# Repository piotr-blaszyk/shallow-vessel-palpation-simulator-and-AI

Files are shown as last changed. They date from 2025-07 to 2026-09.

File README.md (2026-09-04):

# Robot-Assisted Sliding Palpation for Shallow Vessel Localisation with a Calibrated Digital Twin

Locating features **hidden beneath a soft surface** — blood vessels in a silicone phantom,
straws buried under layers of steak — from the deformation of the marker grid of a ViTacTip
optical tactile sensor sliding over it.

The core question: **can a model trained entirely in simulation localise subsurface structure
in the real world?** A digital twin (a Taichi FEM simulation of the sensor pressing on a
phantom with a stiff inclusion) is calibrated against the real sensor by Bayesian optimisation,
generates labelled marker trajectories, and a spatio-temporal graph neural network trained only
on those is evaluated on video from the physical sensor — per marker, and as a top-view vessel
map.

This is a masters project, and a fork of [DiffTactile](https://difftactile.github.io/)
(Si et al., ICLR 2024): the upstream manipulation tasks were removed and the differentiable FEM
core repurposed. The pristine upstream state is preserved at the `upstream-difftactile` tag.

### Project repositories and data

The manuscript — *"Toward Trustworthy Robot-Assisted Sliding Palpation for Shallow Vessel
Localisation with a Calibrated Digital Twin"* — is backed by two repositories and one data
archive:

| Artefact | Role |
|---|---|
| **[shallow-vessel-palpation-simulator-and-AI](https://github.com/piotr-blaszyk/shallow-vessel-palpation-simulator-and-AI)** (this one), DOI [10.5281/zenodo.21958186](https://doi.org/10.5281/zenodo.21958186) | **Main repository.** Simulator, domain adaptation, dataset generation, GNN training and evaluation, all figures and tables — everything needed to reproduce the published results. |
| [shallow-vessel-palpation-robot-control](https://github.com/piotr-blaszyk/shallow-vessel-palpation-robot-control), DOI [10.5281/zenodo.21958190](https://doi.org/10.5281/zenodo.21958190) | Drives the DOBOT Magician E6 arm that collected the real tactile recordings. Needed only to *gather new* data. |
| Zenodo **shallow-vessel-palpation-dataset**, DOI [10.5281/zenodo.21958107](https://doi.org/10.5281/zenodo.21958107) | Datasets, trained checkpoints and the manuscript's figures/tables (~275 MB). See [Data](#data-the-zenodo-bundle). |
| Project page: [piotr-blaszyk.github.io/shallow-vessel-palpation-simulator-and-AI](https://piotr-blaszyk.github.io/shallow-vessel-palpation-simulator-and-AI/) | Abstract and all videos in one place (`docs/`). |

```
   Taichi FEM digital twin                 Real ViTacTip sensor
   sensor + phantom + vessel               video, sliding over the phantom
   (calibrated by Bayesian optimisation)             │
            │                                        ▼
   simulated marker trajectories        tracked marker trajectories
            │                                        │
            └──────────────► ST-GNN ◄────────────────┘
                        train on Sim         test on Sim / Silicone / Meat
                              │
                              ▼
        per-marker vessel probability  ──►  top-view vessel map (1 mm/px)
```

---

## Quickstart (Docker)

**Docker is the only supported way to run this repository.** The image pins the whole stack
(CUDA 12.6, Taichi, PyTorch 2.8 + PyTorch Geometric, PySide6) and passes the host display
through so the simulator's windows work.

**Requirements:** Linux with an NVIDIA GPU (a must), the NVIDIA driver, Docker and the
[NVIDIA Container Toolkit](https://docs.nvidia.com/datacenter/cloud-native/container-toolkit/latest/install-guide.html).
Developed and tested on **Ubuntu 24.04** with an **NVIDIA GeForce RTX 3080 (10 GB)**. Since the
whole stack lives inside the container (Ubuntu 22.04 base image), the host only needs the three
items above, so other Ubuntu releases — including older ones such as 18.04 / 20.04 — should work
too (untested; the optional bare-metal annotator env, `annotate_data_bare_metal.sh`, needs
PySide6 wheels and hence glibc ≥ 2.28, i.e. Ubuntu 20.04+). Less GPU RAM than 10 GB will likely
work as well: the GNN training uses little; the Taichi simulator is the main consumer, and its
budget is set by `TI_DEVICE_MEMORY_GB` (see Troubleshooting). `main` is the only branch.

```bash
# 1. Clone
git clone https://github.com/piotr-blaszyk/shallow-vessel-palpation-simulator-and-AI.git
cd shallow-vessel-palpation-simulator-and-AI

# 2. Fetch the data bundle (~275 MB) and unpack it into place
wget https://zenodo.org/records/21958107/files/shallow-vessel-palpation-data.tar.gz
./data/restore_data.sh shallow-vessel-palpation-data.tar.gz

# 3. Build the image (~10-30 min), start the container, open a shell inside it
cd docker
./docker-build.sh
./docker-run.sh
./docker-connect.sh

# 4. INSIDE the container: verify GPU, dependencies and data
cd docker
./run_pipeline.sh check
```

> **Everything below runs inside the container, from its `docker/` directory**, unless a
> command says otherwise. Every in-container command is equivalent to
> `docker exec -it vessel-palpation ./docker/<script> <args>` from the host. Three scripts are
> launched **from the host** and `docker exec` in by themselves (`view_predictions.sh`,
> `annotate_data_docker.sh`, `record_videos.sh`), and one runs on **bare metal by design**
> (`annotate_data_bare_metal.sh`).

### The pipeline at a glance

Steps 1–2 are done and their outputs ship in the bundle, as do the simulated dataset (step 4)
and the trained models (step 5), so a fresh clone can start anywhere.

1. **Preprocess the real recordings** (Silicone, Meat) → [Real datasets](#real-datasets-annotate-review-preprocess).
2. **Calibrate the digital twin** (`./domain_adaptation.sh`) and adopt the fitted parameters into
   `system-params.json`; draw the validation panels (`./alignment_figures.sh`) →
   [Domain adaptation](#domain-adaptation-calibrating-the-digital-twin).
3. **Pick the temporal window** (`./ablation_clip_len.sh`).
4. **Generate the simulated dataset** (`./run_pipeline.sh sim-full` + reorder) →
   [Regenerate the simulated dataset](#regenerate-the-simulated-dataset).
5. **Train and evaluate the four models** (`./score_all_scenarios.sh --seeds 5`, or one
   configuration with `./run_pipeline.sh <config> --train`) →
   [Reproduce the published results](#reproduce-the-published-results).
6. **Render the qualitative results**: `./vessel_map_all.sh` (top-view maps),
   `./view_predictions.sh` (per-frame viewer), `./record_videos.sh` (the videos below).
7. **Reproduce the poster's analysis** (`./reproduce_analysis.sh`) → [Which script produces
   which figure or table on the poster](#which-script-produces-which-figure-or-table-on-the-poster).

### Which script produces which figure or table in the manuscript

| Script | Produces | Manuscript |
|---|---|---|
| `./annotate_data_bare_metal.sh --silicone` / `--meat` | the annotation viewers | **Fig. 5** (annotated Silicone frame, Meat labels) |
| `./domain_adaptation.sh` → `./alignment_figures.sh` | joint BO calibration; sim (red) vs real (green) marker alignment on the four validation interactions, MAE per panel | **Fig. 4** and the 0.50 mm MAE |
| `./ablation_clip_len.sh` | foreground IoU / AP per temporal window length, mean ± std over seeds | **Table 3** |
| `./score_all_scenarios.sh --seeds 5` | five-seed sweep of every configuration: mean PR curves ± 1 std (ROC twins too), the standalone shared legend (`curve_legend.pdf`) and x label (`xlabel_recall.pdf`), `AUROC_RESULTS.md`, `sweep.json`; `--replot` redraws the curves and legend of an existing sweep without training | **Fig. 6** |
| `python -m difftactile.scripts.script_frame_space_metrics` | per-marker statistics of each best-of-five model, pooled over all central frames → `FRAME_SPACE_METRICS.md` | **Table 4**, upper half |
| `./vessel_map_all.sh` | top-view vessel maps and per-pixel statistics for every configuration | **Fig. 7**, **Table 4** lower half |
| `./record_videos.sh` | the [demonstration videos](#demonstration-videos) | supplementary |
| `./sensor_mesh_screenshots.sh` | three Gmsh screenshots of the ViTacTip mesh from the +x side (level, 45° above, 45° below), lossless WebP in `docs/images/sensor_mesh/` | project page only |

Every mean ± std quotes the five seeds of the published sweep (`saved_models_sweeps/20260815-194045`);
wherever a **single** model is shown or tabulated it is that configuration's **best-of-five
instance by average precision** (`cnn/model_selection.py`) — the convention the manuscript states.

### Which script produces which figure or table on the poster

The conference **poster** reports more than the manuscript: the same four models scored as a
*detection* problem (counts, Hungarian matching, F1 and OSPA), a per-vessel
centreline/centroid decomposition, and a baseline comparison in which **our own predictions
are recomputed under each baseline's own metric definition** rather than being printed beside
numbers that measure a different quantity. All of it lives in
[`analysis/`](analysis/) and is regenerated by one wrapper:

```bash
./docker/reproduce_analysis.sh                  # stages 1-12: every poster figure and number
./docker/reproduce_analysis.sh --with-overlays  # + per-data-point diagnostic overlays (~15 min)
./docker/reproduce_analysis.sh --list           # the stage table
./docker/reproduce_analysis.sh --only 4,7       # re-run individual stages
```

It trains nothing and simulates nothing: it evaluates the four published checkpoints once,
reads the published top-view map runs off disk, and derives everything else from those two.
A full pass is about two minutes, and needs a GPU **for stage 1 only** — the Zenodo bundle
also ships stage 1's output (`analysis/results/frame_space_predictions_<config>.npz`), so
stages 2–12 run on a CPU-only machine. Those four files are the only part of the bundle
`data/restore_data.sh --verify` reports as *regenerable* rather than *missing*: an older
download that predates them still restores cleanly, it just needs
`./docker/reproduce_analysis.sh --only 1` (one GPU minute) run first.

| Poster block | Artefact under `analysis/` | Script (stage) |
|---|---|---|
| **Methods** — *Workflow*: sensor, mesh, simulated interactions, domain randomisation, real datasets, annotation | `figures/workflow/{vitactip,mesh,A1,A2,B1,B2,B3,dr_*,real_*,ann_*}.png` | `make_workflow_images.py` (12) |
| **Methods** — *Workflow*: per-frame prediction block | `figures/workflow/pred_sim_to_meat.png` | `select_sim_to_meat_frames.py` (11) → `make_workflow_images.py` (12) |
| **Methods** — *Workflow*: *Top-view vessel maps* row | `figures/workflow/map_*.png` | `make_workflow_images.py` (12), copied from the published map runs |
| **Methods** — *Workflow*: *Frame-space vessel centrelines and centroids* | `figures/workflow/cl_grid_<0..3>_<config>.png`, `cl_legend.png`, `frame_grid.tex` | `detection_ospa.py` (4) → `workflow_centreline_panels.py` (10) |
| **Methods** — *Workflow*: *Top-view-space vessel centrelines and centroids* | `figures/workflow/cl_map_<config>.png` | `detection_ospa.py` (4) → `workflow_centreline_panels.py` (10) |
| **Methods** — *ST-GNN input graph* | `figures/gnn_graph.png` | `gnn_graph_figure.py` (9) |
| **Results** — take-home box (1.2 mm; AP 0.32 vs 0.30) | `results/symmetric_distances.json`, `figures/pr/ap_values.json` | `symmetric_distances.py` (2), `pr_curves_with_ap.py` (8) |
| **Results** — *Comparison against baselines*, our half of every row | `results/comparable_metrics.json`, `results/symmetric_distances.json` | `comparable_metrics.py` (3), `symmetric_distances.py` (2) |
| **Results** — *Centreline detection and localisation* | `figures/detection_bars.pdf` | `detection_ospa.py` (4) → `detection_bars.py` (7) |
| **Results** — *Segmentation distance* | `figures/segmentation_distance.pdf` | `symmetric_distances.py` (2) → `segmentation_bars.py` (6) |
| **Results** — *Vessel-count confusion* | `figures/detection_confusion.tex` | `detection_ospa.py` (4) → `detection_bars.py` (7) |
| **Results** — *Vessel present or absent* | `figures/binary_confusion.pdf` | `detection_bars.py` (7) |
| **Results** — *Precision–recall curves* | `figures/pr/mean_pr_curve_<config>.pdf`, `curve_legend_vertical.pdf`, `xlabel_recall.pdf` | `pr_curves_with_ap.py` (8) |
| **Results** — *Foreground IoU* | `figures/segmentation_iou.pdf` | `symmetric_distances.py` (2) → `segmentation_bars.py` (6) |

Three poster blocks are **not** repository output and have no script: the Motivation
illustration (hand-made), the *Vessel-detection modalities* table (literature values; the
fully cited version is published at
[`docs/poster-motivation-bibliography/`](docs/poster-motivation-bibliography/)), and the
baselines' own half of the comparison table (read out of each cited paper's full text).

[`analysis/README.md`](analysis/README.md) carries the per-script input/output table, the
self-checks the pipeline performs, the parameters that are judgements rather than fits
(the 5 mm OSPA cutoff, the 2:1 false-alarm/miss weighting, the 3 mm peak-splitting rule)
and the caveats that belong beside every number.

---

## Reproduce the published results

**Naming.** The code uses **A / B / C** for the three datasets; the manuscript spells them out.
`X-to-Y` reads "trained on X, tested on Y":

| Code | Manuscript | Dataset |
|---|---|---|
| **A** | **Sim** | 500 simulated slides (250 with / 250 without the vessel), 317 frames each |
| **B** | **Silicone** | real silicone phantom with shallow vessels: 10 annotated straight-line slides |
| **C** | **Meat** | real meat phantom (metal / silicone straws under 5 mm steaks): 10 trials |

Four (train → test) configurations, each selected **by name** and run either from the published
checkpoint (`--eval`) or retrained (`--train`):

| Config | Manuscript | Model | Default | AUROC | AP | FG IoU | BG IoU |
|---|---|---|---|---|---|---|---|
| `A-to-A` | Sim→Sim | large | `--eval` | 0.958 ± 0.001 | 0.491 ± 0.006 | 0.193 ± 0.019 | 0.818 ± 0.024 |
| `A-to-B` | Sim→Silicone | large | `--eval` | 0.779 ± 0.004 | 0.321 ± 0.004 | 0.234 ± 0.007 | 0.811 ± 0.027 |
| `A-to-C` | Sim→Meat | large | `--eval` | 0.837 ± 0.002 | 0.224 ± 0.004 | 0.171 ± 0.006 | 0.730 ± 0.019 |
| `C-to-B` | Meat→Silicone | compact | `--train` | 0.717 ± 0.054 | 0.304 ± 0.038 | 0.155 ± 0.012 | 0.537 ± 0.124 |

Mean ± std over the five seeds of the published sweep; per-marker over every central frame of
every test trial; IoU at threshold 0.5. `large` is `GNN(arch="large")` (`latent_dim` 256, the
`*_large` keys of the `gnn` config block), `compact` is `latent_dim` 64; a checkpoint only loads
into the architecture it was trained with. `A-to-A`, `A-to-B` and `A-to-C` score the **same**
sim-trained checkpoint on three test sets — the A→A → A→B gap is the sim-to-real transfer cost.

```bash
./run_pipeline.sh A-to-B                 # evaluate the published checkpoint (default for A-to-*)
./run_pipeline.sh C-to-B                 # train on meat, test on silicone (default for C-to-B)
./run_pipeline.sh A-to-C --train         # retrain any configuration from scratch
./run_pipeline.sh all-scenarios          # the four in sequence

./score_all_scenarios.sh                 # one table for all configurations -> AUROC_RESULTS.md
./score_all_scenarios.sh --pretrained    # published checkpoints only
./score_all_scenarios.sh --seeds 5       # retrain each configuration per seed: mean ± std,
                                         # mean PR/ROC curves, saved_models_sweeps/<TS>/
./score_all_scenarios.sh --replot        # redraw the published sweep's mean curves + the
                                         # shared threshold legend from saved scores (no training)
```

Each run prints AUROC, AP (with its chance level and lift) and both IoUs, and writes
`roc_curve_<config>.pdf` / `pr_curve_<config>.pdf` under `difftactile/output/`.
The older names `sim-to-silicone`, `sim-to-meat`, `silicone-to-meat` are accepted as aliases
(the last is a misnomer for A→C). The configuration and mode can also come from
`DIFFTACTILE_SCENARIO` / `DIFFTACTILE_MODE`.

**Training never overwrites the published checkpoints.** A `--train` run writes
`*_retrained_<config>` artifacts (`saved_models_sim/final_segmentation_model_gnn_sim_retrained_A-to-B.pt`
and its `test_loader_gnn_sim_retrained_A-to-B.pickle`, etc.); `DIFFTACTILE_OVERWRITE_PUBLISHED=1`
replaces the published files instead. A checkpoint and its test-loader pickle always travel
together — the pickle holds the normalisation statistics the checkpoint was trained with, and
mismatching them is a silent wrong answer, not an error.

**Metrics.** AUROC and AP are threshold-free (they read only the ranking of the probabilities,
so a domain shift of the output *scale* cannot masquerade as ignorance of where the vessels
are). They are reported together because AUROC normalises false alarms by the huge negative
count while AP ignores true negatives entirely and its chance level is the positive rate
(4–11% here) — the two can disagree in rank, and did on earlier checkpoints. IoU is per class
over the same marker predictions: **foreground** = vessel-present class
(`|pred ∧ true| / |pred ∨ true|`), **background** = vessel-absent class, always the flattering
one (the negative class is ~89% of nodes on Silicone, ~93% on Meat). Unlike AUROC/AP it depends
on the 0.5 threshold. This is the per-marker IoU; the top-view map has its own.

**Seeds.** Training is deterministic (`main/seeding.py`: torch/numpy, the shared `NP_RNG`,
DataLoader workers and deterministic CUDA kernels; default seed 42, `DIFFTACTILE_SEED=N`), so a
run reproduces bit-identically on the same machine. But the spread across seeds is large where
the training set is small — C→B AUROC ranges 0.604–0.779 over seven seeds, wider than any gap
between configurations — so quote a mean ± std, never a single run, and never the best seed.
`--seeds N` runs each seed in a fresh subprocess and keeps every seed's checkpoint + pickle
under `saved_models_sweeps/<timestamp>/<config>_seedNN/` with `sweep.json`.

**Sim test split.** Dataset A is split by trajectory (filenames sorted, cut at 70% / 85% →
350 / 75 / 75), so overlapping windows never leak across splits; every trajectory holds exactly
one vessel, so there is nothing to stratify over. `A-to-A` scores the held-out **test** split
read from the test-loader pickle (never re-derived), not the validation split that drives
early stopping. The test windows are cut at dilation 24 (nine 5-frame windows per 317-frame
trajectory) — which is why the Sim→Sim video below has nine frames.

**Temporal window.** Every sample is a `clip_len` = **5** frame window; the GNN predicts every
frame in it (deep supervision) but only the **central** frame is scored (`dataset.py::get_mask()`,
applied in `segmentation_gnn.shared_step()` for val/test). `DIFFTACTILE_CLIP_LEN` overrides
the window for one process; `./ablation_clip_len.sh [--seeds N]` trains A-to-B at
{1, 3, 5, 7} and writes `CLIP_LEN_ABLATION.md` (Table 3; 5 won on foreground IoU 0.238 vs
0.214 for 7).

---

## Domain adaptation: calibrating the digital twin

> 📄 **Fig. 4** and the marker-alignment MAE (0.50 mm at deepest contact).

The premise only holds if the simulated markers move like the real ones. `./domain_adaptation.sh`
fits the sensor's Young's modulus and the sensor↔vessel contact stiffness by one **joint
Bayesian optimisation**: every iteration simulates **two slides** at the proposed parameters —
vessel-**absent**, scored by marker MAE against the real photograph (fidelity), and
vessel-**present**, scored by how far the vessel holds the sensor up (sensitivity) — and
maximises one objective that trades the two off (`main.py::domain_adaptation_joint`). The
winning configuration is then **validated, not searched**, on the four canonical interactions —
press, twist about *z*, twist about *x*, slide — against one photograph of the real sensor at
each interaction's apex. (An older two-stage design — a vessel-absent search over the sensor
material, then a vessel-present search at the sensor it chose — is obsolete and has been
removed; `DIFFTACTILE_DA_MODE` accepts only `joint`.)

```bash
./domain_adaptation.sh                                # ~35 s per iteration; DIFFTACTILE_BO_JOINT_ITERATIONS=N (default 10),
                                                      # DIFFTACTILE_BO_JOINT_RANDOM=M random iterations first (default 5)
./alignment_figures.sh                                # Fig. 4: white-background panels + MAE, from the
                                                      # published run (or the current parameters)
./score_params.sh                                     # score the CURRENT system-params.json once, no search
./record_da_trajectories.sh                           # record the four interactions to .mp4 (needs a display)
```

Every DA run gets its own `difftactile/output/domain_adaptation/<timestamp>/`
(`bo_joint_results.json`, `iteration_log.csv`, `final_joint_validation.json`,
`da_overlay_<name>.png` on the photograph, `snapshots/` when a display is available). The
published run is `difftactile/output/domain_adaptation_published/joint_bo/` (in the bundle);
`alignment_figures.sh` redraws Fig. 4 from its cached marker positions and reports MAEs
11.9 / 15.8 / 14.5 / 12.4 px (press / twist-z / twist-x / slide; ~55 px = 2 mm marker
spacing). **Adopting a result is manual, deliberately** — nothing writes back into
`system-params.json`.

Details worth knowing: both searched parameters are log-scaled, one decade each — sensor
Young's modulus in [1e5, 1e6] Pa, sensor↔vessel normal stiffness in [1e4, 1e5] (`bo_gp.py`,
`BoGp.__init__` explains the bounds and the CFL limit behind them); a diverged parameter set is
scored as the worst value rather than
aborting; the earlier *differentiable* fit through Taichi was abandoned and its machinery
removed — BO treats the simulator as a black box. The five reference photographs live in
`difftactile/manual_or_experimental_data/domain_adaptation_flat_sensor/` (keys `da_press`,
`da_twist_z`, `da_twist_x`, `da_slide`, `flat_sensor_default_state` in `system-params.json`;
the filename encodes press depth, angle and slide length) and are turned into
`difftactile/output/da_<name>.npz` marker positions automatically. They are unrelated to the
Silicone *training* videos.

Reading the simulator window: the **sensor is green**, the **phantom blue**, the **vessel
yellow** (drawn only when its contact pair is enabled). This is a different convention from
the Fig. 4 overlays, where red = simulated and green = real markers.

---

## Top-view vessel map

> 📄 **Fig. 7** and the lower half of **Table 4**.

Projects the per-marker predictions through the sensor pose onto the phantom plane at
**1 mm per pixel** and renders the top view against the ground truth, for every configuration:

```bash
./vessel_map.sh A-to-B                          # Sim→Silicone, truth reprojected from the annotated video
./vessel_map.sh A-to-B --ground-truth photo     # Sim→Silicone, truth from the phantom's top-view photo
./vessel_map.sh C-to-B                          # Meat→Silicone
./vessel_map.sh A-to-C                          # Sim→Meat: one map per meat trial
./vessel_map.sh A-to-A                          # Sim→Sim: one simulated slide with recorded poses
./vessel_map.sh A-to-A --test-trajectories      # Sim→Sim: the ten trajectories of the prediction video, one map each
./vessel_map_all.sh                             # all six, in one go
./website_vessel_maps.sh                        # the project page's 22 maps -> docs/images/vessel_maps/ (lossless WebP)
./vessel_map.sh A-to-B --model legacy           # pre-2026-08-15 checkpoint (see Legacy models)
./vessel_map.sh A-to-B --threshold 0.6          # override the chosen decision threshold
```

- **Model:** the best-of-five instance by AP (default) or `--model legacy`.
- **Sim→Sim test set:** by default the one dedicated slide (the manuscript's map). With
  `--test-trajectories` the ten held-out trajectories of the project page's Sim→Sim prediction
  video — the same ten, in the same order — each mapped separately. The published dataset
  records no sensor pose, so `./vessel_map_sim_test_trajectories.sh` (~15 min GPU) first
  re-simulates exactly those ten by replaying the dataset's seed, verifies each against the
  published file, and stores the published markers with the re-simulated poses under
  `difftactile/output/vessel_map_sim/test_trajectories/` (shipped in the bundle).
- **Ground truth:** `video` (default) reprojects the test data's own per-marker labels
  (manual annotation on Silicone, kinematics-derived on Meat, the simulator's vessel projection
  on Sim); `photo` (Silicone only) segments the phantom's top-view photograph. Video-vs-photo
  truth IoU is 0.29, which bounds what any model can score against either.
- **The decision threshold is chosen, not assumed:** the one that keeps pixel-level precision
  ≥ 0.9 (a predicted pixel counts within 3 mm of a true pixel) while maximising recall — few
  false alarms over high sensitivity, since a false vessel misdirects a needle while a missed
  one costs a re-scan. If unreachable the run falls back to the F1-optimal threshold and says so
  (measured: Sim→Meat). `--threshold` / `DIFFTACTILE_VESSEL_MAP_THRESHOLD` override.
- **Output is versioned** under `difftactile/output/vessel_maps/<train>-to-<test>_gt-<source>/<timestamp>/`
  and never overwritten: `report.md`, `run.json`, `threshold_selection.png`, and per map
  `prediction.png`, `ground_truth.png`, `confusion_rNN.{png,pdf}` with the truth grown by
  0/1/2 mm, `l2_distances_rNN.png`, `metrics_by_radius.md` (TP FP FN TN MCC F1 precision
  recall accuracy, FG/BG IoU, AP, L2 mean/median/deciles).
- **Colours** (`Visualisation.CONFUSION_COLOURS_RGB`, shared with the viewer): 🟩 green both
  say vessel, 🟥 **red = a miss** (truth says vessel, prediction does not), 🟦 blue = a false
  alarm, ⬛ black neither. Red for misses is deliberate — the missed vessel is the dangerous
  error in palpation.
- **Geometry.** Silicone: the published 180 × 100 mm workspace, plane 16 mm from the lens
  (pressed 3 mm in). Meat: each trial one straight slide along the robot's −y, sensor assumed
  undeformed on the surface (plane 19 mm), all ten maps on one grid. Sim: the recorded
  per-frame pose of one dedicated vessel-present slide (`./vessel_map_sim_trajectory.sh`, seed
  2026, ~2 min; shipped in the bundle) — the published dataset records no poses — with the
  simulator's ×5 length scale (`meta.distance_scaling_factor`).

The **upper half of Table 4** — the same statistics per marker in video-frame space, pooled once
over all central frames of the best-of-five models — is `python -m difftactile.scripts.script_frame_space_metrics`
→ `FRAME_SPACE_METRICS.md`.

### Legacy models

`saved_models_legacy/{sim,meat}/` are the checkpoints (clip_len 7, previous unseeded simulated
dataset) of the version first accepted for publication. They are kept only because they made
that version's vessel-map figure and table; **every current result uses the five-seed sweep at
clip_len 5**. `--model legacy` / `--legacy` load them (they set `DIFFTACTILE_CLIP_LEN=7`); they
cannot be retrained. See `saved_models_legacy/README.md`.

---

## Inspect predictions frame by frame

An interactive viewer over the test set of any configuration: five panels in one Qt window —
Ground Truth, Hard Prediction, Confusion (green both / **red miss** / blue false alarm / grey
neither), Soft Prediction, Metadata — using the best-of-five model by default.

```bash
# from the docker/ directory on the HOST - it execs into the container itself
./view_predictions.sh A-to-B                    # central frames (default)
./view_predictions.sh A-to-C --all              # every frame of every window (debugging view)
./view_predictions.sh A-to-A --trials interleaved:7:3       # 7 vessel-present + 3 vessel-absent held-out trajectories
./view_predictions.sh A-to-A --trials random:10             # ten random held-out simulated trajectories
./view_predictions.sh C-to-B --retrained        # a locally trained model
./view_predictions.sh C-to-B --sweep 20260815-194045 --seed 1   # one seed of a sweep
./view_predictions.sh A-to-B --record out.mp4   # record instead of opening a window
./view_predictions.sh A-to-B --x11              # force X11 instead of Wayland (choppy)
```

| Keys | `--central` (default) | `--all` |
|---|---|---|
| `i` / `o` | previous / next trial | previous / next trial |
| `j` / `k` | previous / next **central frame** | previous / next **clip** |
| `n` / `m` | — | previous / next frame within the clip |
| `q` | quit | quit |

`--central` shows exactly what is scored (one prediction per sliding window, its centre; the
first and last `clip_len // 2` frames of a trial have none). `--all` shows every off-centre
prediction too, on sequential clips. Trials are meat trial directories, silicone videos or
simulated trajectory files; `--trials` takes comma-separated trial-id substrings,
`first-vessel-present`, `random:N` (fixed seed) or `interleaved:P:A` (P vessel-present + A
vessel-absent trials, fixed seed, shown `a a b a a b …`; the project-page Sim→Sim video is
`interleaved:7:3`, and its bird's-eye maps use the identical selection). Trials play in the order
the selection lists them. `--record PATH` steps through everything automatically (one key press
per 500 ms of video), rendered offscreen. The Hard Prediction / Confusion panels use
`MAP_DECISION_THRESHOLD` (0.58, `DIFFTACTILE_MAP_THRESHOLD`) — a display choice only; no
reported metric depends on it. **The viewer shows one model, never an average over seeds**: an
ensemble is a different model whose numbers no table here reports.

---

## Real datasets: annotate, review, preprocess

> 📄 **Fig. 5.**

The two annotation viewers are **Qt (PySide6) applications that run on bare metal by design**,
in a small dedicated environment — hand-driven frame by frame, they need to be responsive, and
they need no Taichi, CUDA or torch:

```bash
micromamba env create -f requirements/annotator-env.yml    # once, ~500 MB

# from the docker/ directory on the HOST
./annotate_data_bare_metal.sh --silicone      # click up to 4 vessel points per frame; g unlocks
                                              # editing, click a point + Delete removes it, z undo,
                                              # d clear frame, m/n video, k/j frame, p save,
                                              # q save+quit, x x quit without saving
./annotate_data_bare_metal.sh --meat          # review-only: red = vessel present, green = absent
                                              # (labels are derived from robot kinematics + straw
                                              # geometry); m/n trial, k/j frame, q quit
./annotate_data_bare_metal.sh --meat --record out.mp4     # record offscreen instead
```

Both are native Wayland clients (PySide6 bundles the Wayland plugin; `QT_QPA_PLATFORM=xcb`
falls back to X11) and open in the container too via `./annotate_data_docker.sh --meat [--x11]`
(host-launched; a debugging twin — the container's Wayland path is as smooth as bare metal, its
X11 path is not). `--meat` works from the bundle (`clean/<trial>/frames.mp4` + `marker_labels.npz`);
`--silicone` needs the dilated videos and annotation pickles, which are **not** in the bundle
(`--source DIR`, see `data/MANIFEST.md`).

**Preprocessing from raw** (only to redo the shipped datasets):

- **Meat** — `python -m difftactile.scripts.script_preprocess_meat_data`: interpolates robot
  poses onto frames, detects and Hungarian-reorders markers, projects the straw geometry from
  [`meat_experiment_spec.md`](difftactile/manual_or_experimental_data/meat_experiment_spec.md)
  through the fisheye model into a label per marker → `clean/<description>-<timestamp>/{marker_positions,marker_labels}.npz`.
  Ten of the 23 recorded trials ship (the rest were repeats no split used); the timestamp is
  the trial's identity, the description only a label. It runs from the shipped `frames.mp4`
  (regenerating, not bit-reproducing: median 0.03 px marker shift); `DIFFTACTILE_MEAT_FROM_RAW=1`
  forces the 1.6 GB raw archive.
- **Silicone** — `python -m difftactile.scripts.script_preprocess_silicone_data`: a chain of
  directory-to-directory stages (interpolate/trim → dilate → markers → reorder → annotate →
  line points → merge → dense labels) ending at the `_dense` directory `files.exp_data_silicone`
  points to. The stages are a commented menu in `preprocess_silicone_data.main()` — uncomment
  the ones you need, in order.
- The viewers as bare modules: `DIFFTACTILE_INTERACTIVE=1 python -m difftactile.scripts.script_annotate_silicone`
  / `script_browse_meat_annotations`.

---

## Regenerate the simulated dataset

The Sim dataset ships in the bundle; run this only to extend the project.

```bash
./run_pipeline.sh sim-short                     # 1 loop (8 trials, ~2-3 min): does the simulator work?
DIFFTACTILE_TRAJECTORIES=3 DIFFTACTILE_VEIN_PAIR=1 DIFFTACTILE_NUM_LOOPS=250 \
    ./run_pipeline.sh sim-full                  # the published shape: 500 slides, half with the vessel
                                                # (seed 42; ~5.5 h on an RTX 3080)

# then Hungarian-reorder into the base-graph order the GNN expects
DIFFTACTILE_SIM_RAW_DIR=difftactile/output/training_data/pickle_<timestamp> \
    python -m difftactile.scripts.script_pre_process_sim_data
# and point files.sim_data in system-params.json at the new ..._reordered_dense directory
```

`run_pipeline.sh sim-*` runs `script_apply_scaling` → `script_pre_main` → `script_main` as
separate processes (`difftactile/scripts/run_all.sh` does the same outside Docker; a single
process would load the config before `apply_scaling` rewrites it). Trajectory types are
0 press, 1 twist about *z*, 2 twist about *x*, 3 slide (`DIFFTACTILE_TRAJECTORIES`; the same
four interactions `generate_trajectories()` builds for domain adaptation); the published
dataset is entirely type 3 with `DIFFTACTILE_VEIN_PAIR=1` (each loop's first substep with the
sensor↔vessel contact pair, so half the trajectories are vessel-present). Collection is seeded,
so the same invocation regenerates the same dataset up to GPU nondeterminism. Raw output is
`difftactile/output/training_data/pickle_<timestamp>/trajectory_XXXX.npz` (`markers`,
`markers_mask`, `vein_polyline`, `vein_classification`, …).

Mesh generation (`script_generate_vitactip_mesh_gmsh`, `script_generate_vein_mesh_gmsh`) and
the sensor-geometry artifacts the simulator loads at start-up ship in the bundle too.

> The simulator opens Taichi GGUI windows when a display is available and **may segfault at
> interpreter exit** (code 139) in GGUI teardown, *after* printing `all done` and writing
> everything — the output is complete. `DIFFTACTILE_HEADLESS=1` avoids it (and is ~35% faster);
> it is implied when `DISPLAY` is unset.

---

## Demonstration videos

All videos live in **[`videos/`](videos/)** (H.264 `.mp4`, ~22 MB in total), made by
`./docker/record_videos.sh` (host-launched) at the parameters in `system-params.json` with the
best-of-five checkpoints; the GUI tools are stepped automatically, one key press per 500 ms of
video, and rendered offscreen (see "Record mode" in `difftactile/main/qt_viewer.py`).

**Simulator** — the four sensor–phantom interactions (sensor **green**, phantom **blue**,
vessel **yellow**), from the simulator's own camera (`record_da_trajectories.sh`):

| | | |
|---|---|---|
| **Press** — [`sim_press.mp4`](videos/sim_press.mp4) | **Twist about x** — [`sim_twist_x.mp4`](videos/sim_twist_x.mp4) | **Twist about z** — [`sim_twist_z.mp4`](videos/sim_twist_z.mp4) |
| **Slide, blood vessel absent** — [`sim_slide_vessel_absent.mp4`](videos/sim_slide_vessel_absent.mp4) | **Slide, blood vessel present** — [`sim_slide_vessel_present.mp4`](videos/sim_slide_vessel_present.mp4) | |

**Domain randomisation** — one vessel-present slide per randomised configuration
(`./docker/record_domain_randomisation_videos.sh`): the slide heading at −15° / 0° / +15° from a
top-down camera (`DIFFTACTILE_CAMERA_VIEW=top`, +y up the image so the slide runs bottom → top)
with both contact coefficients at their midpoint (2.75 × 10⁴, 50), and the 2 × 2 grid of
sensor–vessel normal stiffness {5 × 10³, 5 × 10⁴} × normal damping {0, 100} at heading 0° from
the side view. The three pins — `DIFFTACTILE_SLIDE_HEADING_DEG`, `DIFFTACTILE_VEIN_NORMAL_STIFFNESS`,
`DIFFTACTILE_VEIN_NORMAL_DAMPING` — are read by `record_da_trajectories_main()` only:

| | | |
|---|---|---|
| [`dr_heading_m15.mp4`](videos/dr_heading_m15.mp4) | [`dr_heading_0.mp4`](videos/dr_heading_0.mp4) | [`dr_heading_p15.mp4`](videos/dr_heading_p15.mp4) |
| [`dr_kn5e3_cn0.mp4`](videos/dr_kn5e3_cn0.mp4) | [`dr_kn5e3_cn100.mp4`](videos/dr_kn5e3_cn100.mp4) | |
| [`dr_kn5e4_cn0.mp4`](videos/dr_kn5e4_cn0.mp4) | [`dr_kn5e4_cn100.mp4`](videos/dr_kn5e4_cn100.mp4) | |

**Annotated datasets** — every frame of every recording, stepped through with the annotation
viewers. Silicone: the clicked vessel points. Meat: per-marker labels (red = vessel present,
green = absent):

| | |
|---|---|
| **Silicone phantom** — [`dataset_annotations_silicone.mp4`](videos/dataset_annotations_silicone.mp4) | **Meat phantom** — [`dataset_annotations_meat.mp4`](videos/dataset_annotations_meat.mp4) |

**Per-frame GNN predictions** — the prediction viewer on each configuration's best-of-five
model. Panels: ground truth, hard prediction, confusion (green = both say vessel, red = missed
vessel, blue = false alarm, grey = neither), soft prediction, metadata. Central frames of every
trial for the real datasets; for Sim→Sim ten held-out trajectories (nine dilation-24 windows
each): seven vessel-present and three vessel-absent, each drawn at random with a fixed seed and
interleaved present, present, absent, … — the same ten, in the same order, as the project page's
Sim→Sim bird's-eye maps:

| | |
|---|---|
| **Sim → Sim** — [`predictions_sim_to_sim.mp4`](videos/predictions_sim_to_sim.mp4) | **Sim → Silicone** — [`predictions_sim_to_silicone.mp4`](videos/predictions_sim_to_silicone.mp4) |
| **Sim → Meat** — [`predictions_sim_to_meat.mp4`](videos/predictions_sim_to_meat.mp4) | **Meat → Silicone** — [`predictions_meat_to_silicone.mp4`](videos/predictions_meat_to_silicone.mp4) |

Each link opens the file in GitHub's own video viewer; all videos are also embedded on the
[project page](https://piotr-blaszyk.github.io/shallow-vessel-palpation-simulator-and-AI/).
The robot-control repository carries a video of the real data collection.

---

## Reference

### Data: the Zenodo bundle

**No dataset or checkpoint is in git** (`.gitignore` excludes `*.npz`, `*.pkl`, `*.pt`,
`*.mp4` except `videos/`, `output/`, `saved_models*/`, `logs/`). Everything comes from the
bundle, DOI [10.5281/zenodo.21958107](https://doi.org/10.5281/zenodo.21958107):

```bash
./data/restore_data.sh shallow-vessel-palpation-data.tar.gz   # unpack into place (~275 MB)
./data/restore_data.sh --verify                               # what is present / missing
```

It restores the simulated dataset, the Silicone and Meat datasets, the published checkpoints
and their test-loader pickles, the whole five-seed sweep, the legacy models, the posed Sim→Sim
slide, the sensor-geometry files the simulator loads at start-up, the system-identification
marker tracks, the published domain-adaptation run, the poster analysis's per-marker
predictions (`analysis/results/frame_space_predictions_<config>.npz` — one minute of GPU time,
shipped so stages 2–12 of `./docker/reproduce_analysis.sh` need no GPU at all), and
`difftactile/output/manuscript_artifacts/` (the manuscript's figures and tables, with a README
mapping each to its source — the one "generable but shipped" exception; its `vessel_maps/`
copy is also what the poster analysis reads when the repository has not run the maps itself). Raw videos, intermediate preprocessing stages, superseded
runs and training logs are deliberately excluded — [`data/MANIFEST.md`](data/MANIFEST.md) lists
both sides. `restore_data.sh` takes any local tarball or unpacked directory, so it never needs
Zenodo itself. Authors rebuild the bundle with `./data/make_data_bundle.sh` (bare metal; refuses
to write an incomplete archive) — see `data/ZENODO_UPLOAD.md`.

Without the bundle most entrypoints raise `FileNotFoundError` — including `script_main`, which
loads marker tracks and geometry at construction. Paths resolve against the repository root
(`difftactile/main/paths.py`, override `DIFFTACTILE_ROOT`), so scripts run from any directory.

### Configuration

There are **no command-line flags** beyond the ones documented above; behaviour comes from:

1. **`difftactile/system_params/system-params.json`** — geometry, material and contact
   parameters, trajectories, the `gnn` hyperparameter block, and every path (`files.*`),
   reached in code as `SYSTEM_PARAMS.gnn.clip_len` etc. It is **partly regenerated** by
   `script_apply_scaling` from `system-params-distances.json` (SI metres) and
   `system-params-youngs-modulus.json` — edit *those* for lengths and stiffnesses.
   `system-params-computed.json` is generated by `pre_main.py`; `system-params-units.json` and
   `system-params-literature-values.json` are documentation only; `bo-gp.json` holds BO
   parameters (inert while `meta.load_params_from_bo = 0`).
2. **`RUN_ON_LAB_MACHINE`** in `difftactile/main/main.py` — Taichi on `ti.cuda` (True) or `ti.cpu`.
3. **Environment variables**:

| Variable | Effect |
|---|---|
| `DIFFTACTILE_ROOT` / `DIFFTACTILE_DATA_ROOT` | Repository root for path resolution / keep the real meat trials outside the repository. |
| `DIFFTACTILE_HEADLESS=1` | Create no windows (implied when `DISPLAY` and `WAYLAND_DISPLAY` are unset). |
| `DIFFTACTILE_INTERACTIVE=1` | Restore blocking windows (`plt.show()`, viewers, Gmsh FLTK, the tkinter labeller). Off by default: **no script ever waits for a window**; figures go to `difftactile/output/`. |
| `DIFFTACTILE_SEED` | Seed for every RNG of a training, collection or DA run (default 42). |
| `DIFFTACTILE_NUM_LOOPS`, `DIFFTACTILE_TRAJECTORIES`, `DIFFTACTILE_VEIN_PAIR` | Simulator collection: loops (each = 2 substeps × trajectory types), types to collect, vessel on the first substep. |
| `DIFFTACTILE_SCENARIO`, `DIFFTACTILE_MODE`, `DIFFTACTILE_OVERWRITE_PUBLISHED` | Configuration / `train`\|`eval` when not given as arguments; let training overwrite published checkpoints. |
| `DIFFTACTILE_CLIP_LEN` | Temporal window for one process (positive odd integer; the ablation uses it). |
| `DIFFTACTILE_ARTIFACT_DIR` | Redirect a training run's checkpoint + pickle (the seed sweep uses it). |
| `DIFFTACTILE_MAP_THRESHOLD` / `DIFFTACTILE_VESSEL_MAP_THRESHOLD` | Viewer hard-prediction cut (display only) / vessel-map operating point. |
| `DIFFTACTILE_MAP_CONFIG`, `_GT`, `_MODEL`, `_SEED` | What `vessel_map.sh` passes to `script_vessel_map`. |
| `DIFFTACTILE_VIEW_TRIALS`, `DIFFTACTILE_RECORD_MP4`, `DIFFTACTILE_RECORD_INTERVAL_MS`, `DIFFTACTILE_RECORD_SIZE` | Viewer trial selection; record mode (path, ms of video per key press, window size). |
| `DIFFTACTILE_BO_JOINT_ITERATIONS`, `DIFFTACTILE_BO_JOINT_RANDOM`, `DIFFTACTILE_VEIN`, `DIFFTACTILE_RECORD_TRAJECTORIES`, `DIFFTACTILE_DA_MAX_TIMESTEPS` | Domain adaptation (iterations; random iterations before the acquisition function takes over) / DA recording controls. |
| `DIFFTACTILE_SIM_RAW_DIR`, `DIFFTACTILE_MEAT_FROM_RAW` | Preprocessing inputs. |
| `DIFFTACTILE_ANNOTATOR_PYTHON`, `QT_QPA_PLATFORM` | Interpreter for the bare-metal annotator; force a Qt platform (`xcb`). |

### Repository layout

```
difftactile/
├── main/                    Taichi FEM simulation core: main.py (contact, collection, DA, recording),
│                            pre_main.py, apply_scaling.py, seeding.py, paths.py, display.py, qt_viewer.py
├── sensor_model/            ViTacTip FEM model + fisheye camera projection
├── object_model/            phantom, vessel, mesh loading
├── cnn/                     the GNN: segmentation_gnn.py (the configurations), gnn.py, dataset.py,
│                            seed_sweep.py, clip_len_ablation.py, model_selection.py, curve_plots.py,
│                            frame_space_metrics.py, visualise.py (the prediction viewer)
├── data_analysis/experiment/  real-sensor data: preprocessing, marker tracking, annotation,
│                            calibration, bo_gp.py, vessel_map.py, alignment_figures.py
├── scripts/                 script_<name>.py entrypoint wrappers (each imports a main() and calls it)
├── system_params/           JSON configuration
├── meshes/, manual_or_experimental_data/   STL geometry; reference photos, calibration, specs
docker/                      Dockerfile and every user-facing shell entrypoint
data/                        restore_data.sh, make_data_bundle.sh, MANIFEST.md, ZENODO_UPLOAD.md
analysis/                    the poster's analysis: scripts/ (detection + OSPA scoring,
                             centreline decomposition, baseline-comparable metrics, every
                             poster figure), results/, figures/, reports/
videos/                      the demonstration videos
requirements/                dependency scripts; annotator-env.yml
```

Result tables at the root: `AUROC_RESULTS.md`, `CLIP_LEN_ABLATION.md`, `FRAME_SPACE_METRICS.md`;
the poster's own results are under `analysis/results/` and `analysis/reports/`.
`CLAUDE.md` holds the detailed engineering notes (design decisions, pitfalls, and why things are
the way they are).

### Running outside Docker

Not supported, but possible: Python 3.10–3.12, `pip install uv && pip install -e .`, then
`bash requirements/install_dependencies_difftactile.sh` (Taichi + ML stack; pins CUDA 12.6
wheels and PyG extensions against `torch-2.8.0+cu126`, no lockfile). Set `RUN_ON_LAB_MACHINE = False`
to run the **simulator** on CPU (slowly); the **GNN has no CPU path** —
`cnn/segmentation_gnn.py` allocates on a hardcoded `cuda:0`, so even evaluation needs a GPU.
The container also needs restarting (`docker stop vessel-palpation && ./docker-run.sh`) to pick
up changes to `docker-run.sh` (mounts, ulimits, the Wayland socket); it is started with `--rm`,
so keep work in the bind-mounted repository.

### Modelling decisions to know about

- **Contact compliance is deliberately asymmetric.** The sensor↔phantom pair transfers very
  little deformation; visible sensor deformation is driven almost entirely by the
  sensor↔vessel pair. The simulator is a targeted model of the *inclusion's mechanical
  signature on the marker field* — the quantity the GNN consumes and the one validated against
  the real sensor (Fig. 4) — not a general soft-body contact solver. Treat absolute contact
  forces and phantom deformation as uncalibrated.
- **The phantom is kinematically pinned** (every particle's `is_fixed` flag is set in
  `Phantom.g2p()`), which avoids the MPM collapse and jitter a free phantom showed and does not
  affect the learned quantity.
- **The BO searches only the sensor's Young's modulus (in [1e5, 1e6] Pa) and the
  sensor↔vessel normal stiffness (in [1e4, 1e5]).** Softer sensors (≤ 1e5) and stiffer ones
  (≳ 1.5e6) both diverged, so the box is the surviving decade; the sensor's Poisson's ratio is
  not searched and is held at its `system-params.json` value. `bo_gp.py` records the CFL
  reasoning (a stiffer or more incompressible sensor raises the wave speed at the fixed
  timestep), and the section below lists what else is fixed, fitted or randomised.

### Domain adaptation vs domain randomisation: what is fitted, fixed and randomised

Domain adaptation (`domain_adaptation.sh`, `main.py::domain_adaptation_joint`) *fits* two
simulator parameters against the real sensor; dataset collection (`run_pipeline.sh sim-*`,
`main.py::collect_training_data`) then *randomises* a different pair per trial. Both drive the
same simulator, the same `generate_trajectories()` and the same config, so everything not
listed as fitted or randomised is identical in the two. Lengths are physical (the simulator's
length scale is ×5). World frame: +z is up (the phantom's top-surface normal; gravity is −z);
+x runs along the vessel's axis; +y is the slide direction across the vessel.

| Parameter / setting | Domain adaptation (joint BO) | Domain randomisation (dataset collection) |
|---|---|---|
| 🟰 **Trajectory (waypoints)** | 🟰 Per BO iteration: the **slide** twice — vessel-absent and vessel-present. Final validation (Fig. 4): **press** (phantom centre, 4 mm below the surface), **twist about z** (4 mm, then spin 30°), **twist about x** (off-centre, 2 mm, then tilt 20°), **slide** — all vessel-free. | 🟰 The types named by `DIFFTACTILE_TRAJECTORIES` (0 press, 1 twist about z, 2 twist about x, 3 slide — the same waypoint builders). The published dataset is **slide only**. |
| 🟰 **The slide itself** | 🟰 Same builder in both: two waypoints at a fixed height **3 mm below the phantom's top surface** (no descent phase, no press-depth randomisation); start 30 mm before the phantom centre, end 20 mm past it on the far side, 50 mm of travel, crossing the vessel roughly at right angles. | 🟰 Identical. |
| 🎲 **Slide heading (random)** | 🎲 Drawn **once per run** from `NP_RNG`: −90° ± U(−15°, 15°) about +z, i.e. motion roughly along +y with up to ±15° of yaw of the *path*; every iteration and the validation replay that one heading (seeded, default 42). | 🎲 Re-drawn from the same distribution for **every loop × substep**, so trials differ in heading. |
| 🛑 **Sensor rotation about world +x, +y, +z (random)** | 🛑 **None.** The sensor is held at the configured pose — pointing straight down (180° about +y) and spun by the fixed camera yaw of −10.37° about +z — for the whole slide. | 🛑 **None** (the only rotation draws in the code sit in unreachable helpers and an `if False` block). Same fixed pose. |
| 🟰 **Vessel position / orientation in the phantom** | 🟰 Fixed: centreline along +x at mid-y, **3 mm beneath the top surface** (radius 2 mm, 40 mm long, rigid). | 🟰 Identical (vessel placement randomisation is disabled: `generate_random_state_dicts()` returns `[]`). |
| 🟰 **Vessel present?** | 🟰 Both per iteration (absent → fidelity, present → sensitivity); validation vessel-free. | 🟰 Alternates per **substep** with `DIFFTACTILE_VEIN_PAIR=1` (substep 0 present, substep 1 absent); without it all trials are vessel-free. |
| ❗ **Sensor Young's modulus** | 📈 **Fitted**, log-scaled in [1e5, 1e6] Pa → adopted 881 400 Pa. | 🟰 Fixed at the adopted 881 400 Pa (`vitactip.single_material`). |
| 🟰 **Sensor Poisson's ratio** | 🟰 Fixed at the config value (0.497; not searched). | 🟰 Identical. |
| 🛑 **Phantom Young's modulus / Poisson's ratio** | 🛑 Inert: the phantom is kinematically pinned and takes part in no enabled contact pair, so its material has no effect. | 🛑 Inert, same reason. |
| 🛑 **Vessel Young's modulus / Poisson's ratio** | 🛑 None — the vessel is a rigid signed-distance body with no material parameters. | 🛑 Identical. |
| 🛑 **Sensor↔phantom contact pair** | 🛑 **Disabled** (pair 0; `enable_phantom_contact_pair: false`). | 🛑 **Disabled.** |
| 🛑 **Phantom↔vessel contact pair** | 🛑 **Disabled** (pair 1; never resolved). | 🛑 **Disabled.** |
| ❗ **Sensor↔vessel normal stiffness** | 📈 **Fitted**, log-scaled in [1e4, 1e5] → adopted 94 908. | 🎲 **Random**, U(5e3, 5e4) per loop × substep. |
| ❗ **Sensor↔vessel normal damping** | 🟰 Fixed at 100. | 🎲 **Random**, U(0, 100) per loop × substep. |
| 🛑 **Sensor↔vessel tangential stiffness** | 🛑 0 (i.e. disabled). | 🛑 0 (i.e. disabled). |
| 🛑 **Sensor↔vessel friction coefficient** | 🛑 0 (i.e. disabled). | 🛑 0 (i.e. disabled). |

Legend — one emoji per cell: 🟰 fixed value · 🎲 drawn at random · 📈 fitted by the BO ·
🛑 disabled / zero (a fixed zero counts as disabled). The left-hand column repeats the emoji when
the two regimes agree, and shows ❗ where one regime holds a value fixed that the other varies
(fits or randomises).

How to picture the three rotation axes: a rotation about **+z** spins the sensor about its own
vertical axis — the contact footprint stays put and only the marker pattern turns (the fixed
−10.37° camera yaw, and the 30° "twist about z" validation interaction, are this); a rotation
about **+x** tilts the sensor about the vessel's axis, so it leans forward or back *along the
slide direction* (the 20° "twist about x" interaction); a rotation about **+y** would tilt it
about the slide direction, leaning *along the vessel* — no trajectory in either regime does
this. Neither regime randomises any of the three; the only pose randomness anywhere is the
slide path's heading, and it is the *same* draw (same function, same distribution) in both —
domain adaptation simply takes it once per seeded run, dataset collection once per trial.

Things the table cannot show: a 0 for tangential stiffness or friction switches that term of
the contact force off entirely (`min(k_t·v_t, μ·|F_n|)` is identically zero), so the vessel
pushes on the sensor purely normally in both regimes. Because the sensor↔phantom pair is off,
"press depth" is a commanded height of the sensor relative to the phantom surface, not a
force — the phantom never pushes back, and the vessel is the only thing the sensor touches.
The sensor's Young's modulus is the one parameter that is fitted in one regime and *held at
the fitted value* in the other; the sensor↔vessel normal stiffness is fitted in one and
*randomised over a different range* in the other — the adopted 94 908 lies **above** the
U(5e3, 5e4) the dataset samples, and the fitted-stage damping of 100 is the *top* of the
U(0, 100) the dataset samples. Those two ranges are the dataset's domain randomisation and
predate the joint BO; they were left as collected so the published dataset stays reproducible.
The [project page](https://piotr-blaszyk.github.io/shallow-vessel-palpation-simulator-and-AI/)
shows one simulated vessel-present slide per randomised configuration (heading −15°/0°/+15°,
and the 2 × 2 grid of stiffness × damping range extremes).

### Troubleshooting

| Symptom | Cause / fix |
|---|---|
| `FileNotFoundError` on a `.npz` / `.pkl` / `.pt` | Data bundle not restored — `./data/restore_data.sh --verify`. |
| `received 0 items of ancdata` in training | Container started before `docker-run.sh` raised the fd limit (`ulimit -Sn` should be 65535) — restart it. |
| Viewer says "no Wayland socket" | Container started before the socket mount existed — restart it, or `--x11`. |
| Segfault (139) after `all done` | Taichi GGUI teardown; output is complete. `DIFFTACTILE_HEADLESS=1` for a clean exit. |
| CUDA out of memory in Taichi | Lower `device_memory_GB` in `main.py` (`TI_DEVICE_MEMORY_GB`). |
| Edits to `system-params.json` revert | `script_apply_scaling` regenerates them — edit `system-params-distances.json` / `-youngs-modulus.json`. |
| Different numbers than the tables | Single seed vs five-seed mean; or a `--retrained` model instead of the published one. |

### Limitations

- The domain-randomisation scheme draws three parameters per trial: (1) the sensor's Young's modulus, (2) the sensor–vessel normal stiffness and (3) the approach angle. Because (1) and (2) are drawn from relatively narrow ranges, the diversity within the Sim dataset comes primarily from (3).

### Branches and tags

`main` is the only branch, and the only one the documentation, the image and the bundle are
tested against. The `upstream-difftactile` tag marks the pristine DiffTactile fork point
(`git diff upstream-difftactile..main --stat` shows this project's changes; the history is not
linear from it, so `git log` across it is not meaningful).

---

## Citation

If you use this repository, please cite it (and, where relevant, the companion robot-control
repository and the data bundle) — GitHub's "Cite this repository" button reads the same
metadata from `CITATION.cff`:

```bibtex
@misc{blaszyk_shallow-vessel-palpation-simulator-and-ai_2026,
  title        = {shallow-vessel-palpation-simulator-and-{AI}: a calibrated digital twin and spatio-temporal {GNN} for robot-assisted sliding palpation and shallow vessel localisation},
  author       = {Blaszyk, Piotr and Fan, Wen and Deng, Kaizhong and Elson, Daniel and Zhang, Dandan},
  year         = {2026},
  howpublished = {Zenodo},
  doi          = {10.5281/zenodo.21958186},
  url          = {https://doi.org/10.5281/zenodo.21958186}
}

@misc{blaszyk_shallow-vessel-palpation-robot-control_2026,
  title        = {shallow-vessel-palpation-robot-control: {DOBOT} {Magician E6} control and synchronised tactile-video capture for robot-assisted sliding palpation},
  author       = {Blaszyk, Piotr and Fan, Wen and Deng, Kaizhong and Elson, Daniel and Zhang, Dandan},
  year         = {2026},
  howpublished = {Zenodo},
  doi          = {10.5281/zenodo.21958190},
  url          = {https://doi.org/10.5281/zenodo.21958190}
}

@misc{blaszyk_shallow-vessel-palpation-dataset_2026,
  title        = {shallow-vessel-palpation-dataset},
  author       = {Blaszyk, Piotr},
  year         = {2026},
  howpublished = {Zenodo},
  doi          = {10.5281/zenodo.21958107},
  url          = {https://doi.org/10.5281/zenodo.21958107}
}
```

This work builds on DiffTactile; please also cite the original simulator:

```bibtex
@inproceedings{si2024difftactile,
  title     = {{DIFFTACTILE}: A Physics-based Differentiable Tactile Simulator for Contact-rich Robotic Manipulation},
  author    = {Zilin Si and Gu Zhang and Qingwei Ben and Branden Romero and Zhou Xian and Chao Liu and Chuang Gan},
  booktitle = {The Twelfth International Conference on Learning Representations},
  year      = {2024},
  url       = {https://openreview.net/forum?id=eJHnSg783t}
}
```

## License

MIT — see [LICENSE](LICENSE). Inherited from upstream DiffTactile.

## Contact

Piotr Blaszyk — please open an issue on this repository. Data and weights are on Zenodo at
[10.5281/zenodo.21958107](https://doi.org/10.5281/zenodo.21958107).

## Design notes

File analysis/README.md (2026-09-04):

# `analysis/` — every number and figure of the conference poster

This tree reproduces the **poster** that accompanies the manuscript. The poster reports
more than the manuscript does: the same four models scored as a *detection* problem
(counts, Hungarian matching, F1, OSPA), a per-vessel centreline/centroid decomposition,
and a baseline comparison in which **our own predictions are recomputed under each
baseline's own metric definition** instead of being quoted side by side with numbers that
measure different things.

Nothing here trains a model or runs the simulator. The four published checkpoints are
evaluated once, the published top-view vessel maps are read off disk, and everything else
is derived from those two. One full pass is **under a minute of GPU time and about two
minutes in total** (the optional overlay stages add ~15 minutes).

```bash
# inside the container, from the repository root
./docker/reproduce_analysis.sh                  # stages 1-12: every poster figure and number
./docker/reproduce_analysis.sh --with-overlays  # + the per-data-point diagnostic overlays
./docker/reproduce_analysis.sh --list           # the stage table
./docker/reproduce_analysis.sh --only 4,7       # re-run two stages
```

Prerequisites: the Zenodo data bundle restored (`./data/restore_data.sh`, which brings the
checkpoints, the five-seed sweep, the real datasets and the published top-view map runs) and
a GPU **for stage 1 only** — the bundle also ships stage 1's output, so stages 2–12 run on a
CPU-only machine.

## Layout

```
analysis/
├── scripts/     the 16 scripts below; paths.py resolves every input and output
├── assets/      the one non-generated input (the pipeline overview figure, cropped for
│                the ViTacTip photograph of the workflow diagram)
├── results/     machine-readable output: *.json (tracked) and *.npz (gitignored, shipped
│                in the Zenodo bundle because they need a GPU)
├── figures/     every figure the poster prints (tracked)
├── reports/     Markdown write-ups generated from results/ (tracked)
└── overlays/    optional per-data-point diagnostic renders (gitignored)
```

`scripts/paths.py` derives every path from its own location, so the tree needs no editing
after a clone. It also resolves the **published top-view map run** of each configuration:
the newest timestamp under `difftactile/output/vessel_maps/<cfg>/` if the repository has run
the maps itself, otherwise the copy the bundle restores into
`difftactile/output/manuscript_artifacts/vessel_maps/<cfg>/`. Runs are never overwritten and
`data/make_data_bundle.sh` stages the newest one, so "newest" and "published" cannot drift
apart.

## Which script produces which poster block

Column headings are the poster's own. `A / B / C` are the code's dataset names
(Sim / Silicone / Meat); `X-to-Y` reads "trained on X, tested on Y".

| Poster block | Artefact | Script (stage) |
|---|---|---|
| **Motivation** — opening illustration | — | Hand-made illustration; not derived from any measurement. |
| **Motivation** — *Vessel-detection modalities* | — | Literature values, not repository output. The fully cited version of the table is published at [`docs/poster-motivation-bibliography/`](../docs/poster-motivation-bibliography/). |
| **Motivation** — *Contributions* | — | Prose. |
| **Methods** — *Workflow*, sensor / mesh / simulated interactions / domain randomisation / real datasets / annotation blocks | `figures/workflow/{vitactip,mesh,A1,A2,B1,B2,B3,dr_heading,dr_stiffness,real_*,ann_*}.png` | `make_workflow_images.py` (12) |
| **Methods** — *Workflow*, per-frame prediction block | `figures/workflow/pred_sim_to_meat.png` | `select_sim_to_meat_frames.py` (11) → `make_workflow_images.py` (12) |
| **Methods** — *Workflow*, *Top-view vessel maps* row | `figures/workflow/map_*.png` | `make_workflow_images.py` (12), copied from the published map runs |
| **Methods** — *Workflow*, *Frame-space vessel centrelines and centroids* | `figures/workflow/cl_grid_<0..3>_<config>.png`, `cl_legend.png`, `frame_grid.tex` | `detection_ospa.py` (4) → `workflow_centreline_panels.py` (10) |
| **Methods** — *Workflow*, *Top-view-space vessel centrelines and centroids* | `figures/workflow/cl_map_<config>.png` | `detection_ospa.py` (4) → `workflow_centreline_panels.py` (10) |
| **Methods** — *ST-GNN input graph* | `figures/gnn_graph.png` | `gnn_graph_figure.py` (9) |
| **Results** — take-home box | 1.2 mm; AP 0.32 vs 0.30 | `symmetric_distances.py` (2), `pr_curves_with_ap.py` (8) |
| **Results** — *Comparison against baselines*, our half of every row | `results/comparable_metrics.json`, `results/symmetric_distances.json` | `comparable_metrics.py` (3), `symmetric_distances.py` (2) |
| **Results** — *Comparison against baselines*, the baselines' half | — | Read out of each cited paper's own full text; not repository output. |
| **Results** — *Centreline detection and localisation* | `figures/detection_bars.pdf` | `detection_ospa.py` (4) → `detection_bars.py` (7) |
| **Results** — *Segmentation distance* | `figures/segmentation_distance.pdf` | `symmetric_distances.py` (2) → `segmentation_bars.py` (6) |
| **Results** — *Vessel-count confusion* | `figures/detection_confusion.tex` | `detection_ospa.py` (4) → `detection_bars.py` (7) |
| **Results** — *Vessel present or absent* | `figures/binary_confusion.pdf` | `detection_bars.py` (7) |
| **Results** — *Precision–recall curves* | `figures/pr/mean_pr_curve_<config>.pdf`, `curve_legend_vertical.pdf`, `xlabel_recall.pdf`, `ap_values.json` | `pr_curves_with_ap.py` (8) |
| **Results** — *Foreground IoU* | `figures/segmentation_iou.pdf` | `symmetric_distances.py` (2) → `segmentation_bars.py` (6) |
| **Results** — *Limitations*, *Future work* | — | Prose. |

Model colours (light Sim→Sim to dark Meat→Silicone) are defined once in
`scripts/model_colours.py`; every figure script imports them, and running that script prints
the matching LaTeX `\definecolor` block.

## The scripts, in dependency order

| # | Script | Reads | Writes |
|---|---|---|---|
| 1 | `frame_space_predictions.py` | the four published checkpoints + their test-loader pickles | `results/frame_space_predictions_<config>.npz` — per-marker probability, label, pixel position, trial and frame index of every central frame |
| 2 | `symmetric_distances.py` | (1), the published map runs | `results/symmetric_distances.{json,md}` — foreground IoU and four distance definitions, video-frame and top-view space |
| 3 | `comparable_metrics.py` | (1) | `results/comparable_metrics.json` — our predictions under each baseline's own metric |
| 4 | `detection_ospa.py` | (1), the published map runs | `results/detection_ospa.json` — counts, matching, precision/recall/F1, OSPA, at cutoffs 5 mm and 1 mm |
| 5 | `detection_ospa_report.py` | (4) | `reports/detection-ospa.md` |
| 6 | `segmentation_bars.py` | (2) | `figures/segmentation_iou.pdf`, `figures/segmentation_distance.pdf` |
| 7 | `detection_bars.py` | (1), (4) | `figures/detection_bars.pdf`, `figures/detection_confusion.tex`, `figures/binary_confusion.pdf` |
| 8 | `pr_curves_with_ap.py` | the published five-seed sweep | `figures/pr/*` |
| 9 | `gnn_graph_figure.py` | `difftactile/output/base-graph-connectivity.npz` | `figures/gnn_graph.png` |
| 10 | `workflow_centreline_panels.py` | (1), (4), the published map runs | `figures/workflow/cl_*`, `figures/workflow/frame_grid.tex`, `results/workflow_panel_choice.json` |
| 11 | `select_sim_to_meat_frames.py` | (1), the meat dataset | `overlays/sim_to_meat_frame_choice/<timestamp>/` |
| 12 | `make_workflow_images.py` | `docs/videos/`, `docs/images/sensor_mesh/`, `assets/`, the published map runs, (11) | `figures/workflow/*.png` |
| 13 | `centreline_overlays.py` *(optional)* | (1), the published map runs | `overlays/centrelines/<timestamp>/` — one per-vessel overlay per scored data point |
| 14 | `detection_overlays.py` *(optional)* | (1), (4) | `overlays/detections/<timestamp>/` — the same for the detection/OSPA extraction |
| — | `paths.py`, `model_colours.py` | — | imported by the rest; not entry points |

## Self-checks

The pipeline refuses to produce a plausible-looking wrong answer:

* **Stage 1 asserts** the pooled TP/FP/FN/TN of each configuration at threshold 0.5 against
  `FRAME_SPACE_METRICS.md` (the manuscript's Table 4, upper half). A wrong checkpoint, a
  wrong test split or a mismatched normalisation pickle fails there rather than silently
  shifting every number downstream.
* **Stage 2 prints** its recomputed one-directional map distance and foreground IoU beside
  the manuscript's Table 4 values; they agree to the printed precision
  (1.05 / 1.21 / 5.49 / 1.31 mm and 0.42 / 0.28 / 0.21 / 0.31).
* **Stages 4 and 10 validate the object extraction against physical ground truth**: the
  recovered ground-truth vessel counts are 1 on the Sim map, 10 on each silicone
  whole-phantom map (the ten sweeps recorded in the run's `run.json`) and
  1/1/1/1/1/1/1/2/3/0 across the ten meat trials — which matches every trial directory name,
  including the `no-straw` control.

## Parameters that are choices, not fits

Stated here because they are the ones a reader should be able to disagree with:

* **OSPA cutoff `c` = tolerance `τ` = 5.0 mm**, a clinical usefulness judgement, not tuned
  on the data; `detection_ospa.py` evaluates and reports **1.0 mm** (the IV-needle-access
  margin) as well, and both are in `results/detection_ospa.json`.
* **`α_FP` = 2, `α_FN` = 1** — a false vessel costs twice a missed one, because a phantom
  vessel sends a needle into tissue while a missed one only forfeits the assist.
* **Frame-space threshold 0.5** everywhere; the top-view maps use each configuration's own
  chosen operating point (precision ≥ 0.9, maximise recall), which is the manuscript's rule.
* **`R_SPLIT` = 3.0 mm**, the distance below which two score peaks may not split one
  connected component — chosen to sit above the marker pitch (1.8–2.0 mm) and below the
  smallest true vessel separation in these datasets (3.5 mm). A dataset with vessels closer
  than that needs the rule re-derived.
* **DBSCAN `eps`** — frame space 1.45 × the dataset's median marker spacing; map space 3 mm
  with `min_samples` 3 and clusters under 5 px dropped.

## Known caveats, all of them in the reports

* Every distance printed is **precision-side only**: it scores the elements the model
  predicted to be vessel. The map recalls behind those numbers are 0.79 / 0.44 / 0.86 / 0.47.
* The detection cells of the baseline comparison show the hit half. The matching
  **false-alarm rates on vessel-free frames** are 0.23 (Sim→Silicone), 0.52 (Sim→Meat) and
  1.00 (Meat→Silicone) — `results/comparable_metrics.json`, field `false_alarm_rate`.
* The lateral error is computed **per frame with all vessels merged** into one principal
  axis, not per vessel. Recomputing it per matched vessel pair gives 1.17 ± 1.34 mm on
  Sim→Silicone against the 1.88 ± 1.98 mm reported, so the merge makes the reported number
  *worse*, not better.
* `matched_mean_mm` (mean distance over matched pairs only) is reported but is misleading in
  isolation: on the silicone map the assignment pairs sweeps at opposite ends of the phantom,
  giving 13.87 mm against 1.38 mm over the pairs inside the tolerance. Read OSPA and F1
  together instead.

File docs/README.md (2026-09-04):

# Project page

`index.html` is the GitHub Pages site (served from `main`, `/docs`):
https://piotr-blaszyk.github.io/shallow-vessel-palpation-simulator-and-AI/

`videos/` are **copies** of `../videos/` (this repository) plus the two data-collection files
from the robot-control repository, because raw.githubusercontent.com serves `.mp4` as
`application/octet-stream` with `nosniff`, which some browsers refuse to play. After
re-recording (`docker/record_videos.sh`) copy the new files here again. The seven `dr_*.mp4`
domain-randomisation slides are written here directly by
`docker/record_domain_randomisation_videos.sh` (heading ±15°/0° from a top-down camera, the 2 × 2
grid of sensor–vessel stiffness × damping range extremes from the side view).

`images/sensor_mesh/` holds the three screenshots of the ViTacTip mesh (side, 45° above, 45° below)
(lossless WebP, ~20 kB each), written directly here by `docker/sensor_mesh_screenshots.sh`.

`images/vessel_maps/` holds the 22 top-view vessel maps (lossless WebP, ~0.1–2 kB each) written
directly here by `docker/website_vessel_maps.sh`: Sim→Sim ×10 (the ten trajectories of the
Sim→Sim prediction video, in the video's order — `docker/vessel_map_sim_test_trajectories.sh`
must have re-simulated them with poses first), Sim→Silicone ×1, Sim→Meat ×10 (the video's trial
order), Meat→Silicone ×1. `manifest.md` beside them names the run each came from. After
re-recording the Sim→Sim video or retraining, re-run both scripts so the page's "same
trajectories, same order" statement stays true.

`images/centrelines/` holds the 20 vessel-centreline/centroid panels (lossless WebP, ~17–62 kB
each) written directly here by `docker/website_centreline_panels.sh`: 16 frame-space panels
(ground-truth vessel count 0–3 × the four models) and 4 top-view panels, one per model. They are
the same panels the poster's workflow diagram carries, drawn with `--all-axes` so that all
sixteen come out the same size — a web grid scales every cell to one width, and the poster's
flush layout (axes on the left column and bottom row only) would render them at visibly
different sizes here. `manifest.md` beside them records which frame each cell shows, why it was
chosen and the numbers quoted in its caption. The script needs
`analysis/results/frame_space_predictions_*.npz`, so run `docker/reproduce_analysis.sh` (or
restore the Zenodo bundle) first; re-run both after retraining, or the page's numbers go stale.

`poster-motivation-bibliography/` is a standalone LaTeXML page: the poster's
"Vessel-detection modalities" table with every claim cited. It is light-theme only.

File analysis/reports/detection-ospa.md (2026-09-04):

# Vessel localisation scored as a detection problem: counts, matching and OSPA

*2026-09-04. Companion to `reports/ours-same-metric-derivations.md` and
`reports/vessel-centreline-derivations.md`. Generated by `scripts/detection_ospa_report.py`
from `results/detection_ospa.json`; the numbers are never retyped.*

---

## Why

Every distance on the poster is a mean over things that were assumed to correspond: pixel to
nearest pixel, centroid to centroid. None of them says how many vessels the model found, and a
mean over matched objects quietly rewards a model that predicts the one easy vessel and skips
the hard ones. A frame or a map here holds **0, 1, 2 or 3** vessels, so the task is a detection
problem, and it is scored the way object detection and multi-target tracking are scored:
extract objects, match them, then report **counts**, **detection rates** and **localisation
error** separately, plus one penalised scalar for model selection.

## The metric

Objects are matched with the Hungarian algorithm and scored with **OSPA** (Schuhmacher, Vo &
Vo, 2008), the standard distance between two sets of different cardinality, with an asymmetric
cardinality penalty:

```
d = [ SUM_matched min(d_i, c)  +  c * (a_FP * FP + a_FN * FN) ] / max(m, n)
```

| parameter | value | where it comes from |
|---|---|---|
| `c` = `tau` | **5 mm** | the clinical usefulness threshold: the distance beyond which a localisation is useless here. Set by judgement, not tuned on the data. |
| `a_FP` | **2** | a false vessel costs twice a missed one: it sends a needle into tissue, whereas a miss only forfeits the assist. |
| `a_FN` | **1** | reference weight. |
| `p` | **1** | so OSPA is an average in millimetres. |

`m` = predicted objects, `n` = true objects. Because both weights are >= 1, pairing is never
dearer than leaving a pair unmatched, so the optimal assignment matches `min(m, n)` objects and
the cardinality error is `|m - n|`. Two empty sets score 0; the metric is bounded above by
`max(a_FP, a_FN) * c` = **10 mm**, the score of a data point that is all false alarms.

The cutoff was **1 mm** when this was first written (the error margin for IV needle access)
and was raised to **5 mm** by the user on 2026-09-04. Both are reported below rather than
only the current one, because the choice of `c` is a judgement and it moves every number.

Reported **beside** OSPA, never instead of it, because OSPA alone cannot separate a
localisation error from a detection error: the count confusion matrix, precision / recall / F1
at `tau`, and the mean distance over matched pairs.

## Extraction

Two object types, because "where is the vessel" has two natural answers:

* **centreline** --- one straight segment per vessel, total-least-squares fit. Distance between
  two centrelines is the symmetric mean point-to-segment distance (25 samples per segment).
* **centroid** --- one point per vessel. Distance is plain Euclidean, in mm.

...and two spaces, which differ in what is on disk:

* **Video-frame space** carries the model's **per-marker probabilities** (`probs` in the saved
  npz, 0.10--0.999), so the prediction side uses a **heatmap head**: non-maximum suppression over
  the score field picks peaks, every above-threshold marker joins its nearest peak, and each
  object's centroid and axis are **score-weighted**, which localises below the ~2 mm marker
  pitch. Plain radial NMS would shred an elongated vessel into one object per bump, so a peak is
  only allowed to split a connected component when the peaks are more than `R_SPLIT` = 3.0 mm
  apart **and** the score dips below 0.80 x the weaker peak between them --- a watershed in spirit.
  `R_SPLIT` sits below the smallest true vessel separation in the data (3.5 mm) and above the
  marker pitch (1.8--2.0 mm).
* **Top-view map space** has only the thresholded masks on disk --- no probability map is saved by
  the map builder --- so extraction there is plain connected components with an unweighted
  centroid and axis, and **no heatmap head is used**.

Near-duplicates are merged in both spaces so a fragmented mask cannot over-count: centroids
closer than 2 mm, or centrelines within 12 deg of each other, offset by less than 2 mm
**and overlapping along their shared axis**. That last clause matters: without it the silicone
phantom's left- and right-hand sweeps of the same row, which are collinear but disjoint, were
fused into one object and the ground-truth count came out as 8 instead of 10.

### The extraction is validated against physical ground truth

The recovered **ground-truth** object count is right on every top-view trial, for both object
types:

| map | recovered | physically present |
|---|---|---|
| Sim->Sim, whole map | 1 | 1 simulated vein |
| Sim->Silicone / Meat->Silicone, whole map | 10 | "silicone phantom, ten sweeps" (`run.json`) |
| Sim->Meat trials 01--07 | 1 each | `1-metal-straw-...`, `1-silicone-straw-...` |
| Sim->Meat trial 08 | 2 | `2-metal-straws-beneath-2-steaks` |
| Sim->Meat trial 09 | 3 | `3-metal-straws-beneath-2-steaks` |
| Sim->Meat trial 10 | 0 | `no-straw` |

---

## Results at c = tau = 5 mm

### Centrelines

| config | space | n | count acc. | count MAE | P | R | F1 | matched-pair mean | within `tau` | **OSPA** |
|---|---|---|---|---|---|---|---|---|---|---|
| Sim->Sim | video frame | 675 | 0.90 | 0.13 | 0.81 | 0.90 | 0.85 | 1.50 mm (n=298) | 1.35 mm (n=290) | **0.91 mm** |
| Sim->Sim | top-view map | 1 | 1.00 | 0.00 | 1.00 | 1.00 | 1.00 | 0.36 mm (n=1) | 0.36 mm (n=1) | **0.36 mm** |
| Sim->Silicone | video frame | 120 | 0.63 | 0.54 | 0.68 | 0.88 | 0.77 | 2.08 mm (n=133) | 1.77 mm (n=127) | **3.20 mm** |
| Sim->Silicone | top-view map | 1 | 0.00 | 3.00 | 0.38 | 0.50 | 0.43 | 13.87 mm (n=10) | 1.38 mm (n=5) | **4.76 mm** |
| Sim->Meat | video frame | 219 | 0.36 | 1.07 | 0.32 | 0.61 | 0.42 | 3.63 mm (n=123) | 2.23 mm (n=100) | **5.07 mm** |
| Sim->Meat | top-view map | 10 | 0.70 | 1.00 | 0.17 | 0.25 | 0.20 | 9.81 mm (n=10) | 3.07 mm (n=3) | **5.30 mm** |
| Meat->Silicone | video frame | 120 | 0.24 | 1.88 | 0.27 | 0.57 | 0.37 | 4.02 mm (n=114) | 2.30 mm (n=83) | **5.97 mm** |
| Meat->Silicone | top-view map | 1 | 0.00 | 4.00 | 0.43 | 0.60 | 0.50 | 8.09 mm (n=10) | 1.80 mm (n=6) | **5.06 mm** |

### Centroids

| config | space | n | count acc. | count MAE | P | R | F1 | matched-pair mean | within `tau` | **OSPA** |
|---|---|---|---|---|---|---|---|---|---|---|
| Sim->Sim | video frame | 675 | 0.90 | 0.13 | 0.73 | 0.82 | 0.77 | 2.00 mm (n=298) | 1.42 mm (n=263) | **1.04 mm** |
| Sim->Sim | top-view map | 1 | 1.00 | 0.00 | 1.00 | 1.00 | 1.00 | 0.75 mm (n=1) | 0.75 mm (n=1) | **0.75 mm** |
| Sim->Silicone | video frame | 120 | 0.63 | 0.54 | 0.52 | 0.67 | 0.59 | 3.63 mm (n=133) | 2.07 mm (n=97) | **3.73 mm** |
| Sim->Silicone | top-view map | 1 | 0.00 | 3.00 | 0.38 | 0.50 | 0.43 | 19.02 mm (n=10) | 2.20 mm (n=5) | **5.08 mm** |
| Sim->Meat | video frame | 219 | 0.36 | 1.07 | 0.33 | 0.64 | 0.44 | 3.90 mm (n=123) | 2.34 mm (n=105) | **5.06 mm** |
| Sim->Meat | top-view map | 10 | 0.70 | 1.00 | 0.39 | 0.58 | 0.47 | 4.97 mm (n=10) | 1.73 mm (n=7) | **3.95 mm** |
| Meat->Silicone | video frame | 120 | 0.24 | 1.88 | 0.28 | 0.59 | 0.38 | 4.17 mm (n=114) | 2.29 mm (n=85) | **5.89 mm** |
| Meat->Silicone | top-view map | 1 | 0.00 | 4.00 | 0.29 | 0.40 | 0.33 | 33.18 mm (n=10) | 1.16 mm (n=4) | **5.33 mm** |

### How the cutoff moves the answer

Video-frame space, centrelines. `c` scales OSPA, so the values are not comparable across
columns; the **ordering** is, and it is the same at both cutoffs.

| config | F1 @ 5 mm | F1 @ 1 mm | OSPA @ 5 mm | OSPA @ 1 mm |
|---|---|---|---|---|
| Sim->Sim | 0.85 | 0.38 | 0.91 mm | 0.35 mm |
| Sim->Silicone | 0.77 | 0.27 | 3.20 mm | 0.92 mm |
| Sim->Meat | 0.42 | 0.07 | 5.07 mm | 1.14 mm |
| Meat->Silicone | 0.37 | 0.08 | 5.97 mm | 1.36 mm |

### OSPA split by whether a vessel is actually there (video-frame space, centrelines)

A vessel-free data point scores 0 when the model also says "nothing", and Sim->Sim has 379 of
them, which flatters its pooled mean. Split out:

| config | all frames | vessel-bearing | vessel-free |
|---|---|---|---|
| Sim->Sim | 0.91 mm (n=675) | 2.07 mm (n=296) | 0.00 mm (n=379) |
| Sim->Silicone | 3.20 mm (n=120) | 3.44 mm (n=94) | 2.31 mm (n=26) |
| Sim->Meat | 5.07 mm (n=219) | 4.96 mm (n=129) | 5.22 mm (n=90) |
| Meat->Silicone | 5.97 mm (n=120) | 4.85 mm (n=94) | 10.00 mm (n=26) |

### Count confusion, video-frame space, centrelines (rows = true count, columns = predicted)

Counts do not depend on the cutoff.

**Sim->Sim**

| true \ pred | 0 | 1 | 2 | 3 | 4+ |
|---|---|---|---|---|---|
| **0** | 379 | 0 | 0 | 0 | 0 |
| **1** | 0 | 229 | 21 | 20 | 0 |
| **2** | 0 | 24 | 1 | 1 | 0 |

**Sim->Silicone**

| true \ pred | 0 | 1 | 2 | 3 | 4+ |
|---|---|---|---|---|---|
| **0** | 20 | 4 | 2 | 0 | 0 |
| **1** | 2 | 20 | 8 | 9 | 4 |
| **2** | 0 | 10 | 36 | 4 | 1 |

**Sim->Meat**

| true \ pred | 0 | 1 | 2 | 3 | 4+ |
|---|---|---|---|---|---|
| **0** | 43 | 20 | 7 | 11 | 9 |
| **1** | 16 | 31 | 37 | 12 | 7 |
| **2** | 0 | 9 | 5 | 3 | 0 |
| **3** | 0 | 7 | 2 | 0 | 0 |

**Meat->Silicone**

| true \ pred | 0 | 1 | 2 | 3 | 4+ |
|---|---|---|---|---|---|
| **0** | 0 | 3 | 3 | 2 | 18 |
| **1** | 0 | 14 | 10 | 14 | 5 |
| **2** | 0 | 31 | 15 | 5 | 0 |

---

## Pictures of the final matched state

`scripts/detection_overlays.py` draws one image per data point showing **exactly the objects
scored above**, after filtering and after matching --- no candidate peaks, no pre-merge
fragments. Current run: **`analysis/overlays/detections/<stamp>`**
(3465 images, 179 MB, `tau` = 5 mm).

| style | meaning |
|---|---|
| magenta / orange | ground truth / prediction |
| solid, label `k` | matched pair, within the tolerance |
| solid thin, label `k*` | matched pair, but farther apart than the tolerance |
| dashed line, hollow dot, label `(k)` | **unmatched** object |

A magenta `k` and an orange `k` are the same pair; an index that appears in only one colour is
unmatched. Markers and pixels keep the confusion colours (TP green, FN red, FP blue, TN grey),
and every title lists the pair distances and that data point's OSPA. Three variants per data
point: `centreline/`, `centroid/`, and `both/` (the centreline objects with their segment and
their centroid drawn together, matched as centrelines). The bulk frame-space images and the
contact sheets are git-ignored; the top-view images and the manifests are tracked.

---

## What the numbers say

**OSPA orders the four transfers, and it is the first single number on this project that
does.** Video-frame space, centrelines: Sim->Sim **0.91**, Sim->Silicone **3.20**, Sim->Meat **5.07**, Meat->Silicone **5.97** mm; F1 at the same
tolerance runs 0.85 / 0.77 / 0.42 / 0.37 in the same order. The
poster's distance columns do not order them this way, because they never charge for a vessel
that was invented or missed.

**Sim->Sim is the one configuration that works.** Its top-view map finds exactly one vessel where
there is exactly one, at 0.36 mm, with precision, recall and F1 all 1.00. Per frame it holds
up too: 290 true detections against 70 false alarms and 32 misses (P 0.81, R 0.90), and
the pairs it does make sit 1.35 mm apart on average.

**Detection degrades faster than localisation.** On Sim->Silicone the model still finds most vessels
(F1 0.77 per frame) but its OSPA is 3.20 mm; by Meat->Silicone F1 is 0.37 and OSPA 5.97 mm.
Count accuracy tells the same story: 0.90 -> 0.63 -> 0.36 -> 0.24. The confusion matrices show where it goes ---
Sim->Meat and Meat->Silicone over-predict, splitting one vessel into two or three, or inventing them where the
ground truth is empty.

**The matched-only distance is not a metric on its own, and the silicone map proves it.** There
the mean over all matched pairs is **13.87 mm**: with 10 true sweeps and 13 predicted objects,
the Hungarian assignment pairs a sweep at one end of the phantom with one at the other. Restrict
to pairs inside the tolerance and it falls to 1.38 mm over 5 pairs --- a different quantity
entirely. Both are in the tables above so the gap is visible.

**The asymmetric penalty does the work it was asked to do.** Meat->Silicone's 26 vessel-free frames score
OSPA **10.00 mm** --- the maximum the metric can take, `max(a_FP, a_FN) * c` = 10 mm --- because
every one of them contains a false alarm and a false alarm is charged twice a miss. That is the
100 % false-alarm rate, which the poster keeps as spoken material, produced by the metric itself.

**Raising the cutoff from 1 mm to 5 mm changes the verdict from "nothing works" to "one
thing works and the rest are noisy".** At 1 mm almost no pair survived the gate, so every
detection rate was near zero and OSPA was dominated by the cardinality term; at 5 mm the
detection rates become informative and the localisation error starts to matter. Neither cutoff
is more correct --- 1 mm is the needle-access margin, 5 mm is nearer a vessel diameter --- which
is why both are in the table above.

## Caveats

* **This is a heatmap head bolted onto a segmentation head, not a trained one.** The saved
  per-marker probabilities are used as the score field, which is the right thing to do with what
  is on disk, but a model trained to regress a Gaussian at each vessel would give points directly
  instead of inheriting segmentation errors non-linearly. Changing that is a model-design change
  and a retraining job, not a metric recomputation.
* **Top-view space gets no heatmap head at all**, because the map builder saves only thresholded
  masks. It holds a float `maxprob` map in memory (`vessel_map.py::MapData.maxprob`) and discards
  it. Saving it would let the same extraction run there, and would very likely improve the
  top-view counts, where the silicone map over-counts 10 true sweeps as 13.
* **OSPA scales with `c`.** An absolute value is not "the system is 5 mm accurate"; it is a
  blend of localisation error and cardinality error on a scale set by the cutoff. Read the
  ordering and the F1 column, not the millimetres alone.
* **The `R_SPLIT` = 3.0 mm splitting rule is data-dependent.** It works because the smallest true
  vessel separation in these datasets is 3.5 mm. A dataset with vessels closer than that would
  need the rule re-derived, or a proper watershed on a distance transform.

## Reproduction

```bash
python analysis/scripts/detection_ospa.py         # analysis/results/detection_ospa.json  (~4 min)
python analysis/scripts/detection_ospa_report.py  # this file
python analysis/scripts/detection_overlays.py     # the overlays  (~7 min, 3465 images)
```

`detection_ospa.py --cutoffs 5 1` sets the cutoffs; `detection_overlays.py
--tau 5` sets the one the pictures are drawn at. All parameters are recorded in the JSON's
`params` block and in each overlay run's `params.json`.

## Quotable summary

One sentence, for a caption or an abstract:

> Scored as a detection problem at a 5 mm tolerance (OSPA, false alarms weighted twice
> misses): Sim->Sim 0.91 mm, Sim->Silicone 3.20 mm, Sim->Meat 5.07 mm, Meat->Silicone 5.97 mm.
> Sim->Sim is the only configuration whose top-view map achieves perfect detection
> (F1 = 1.00) inside that tolerance.

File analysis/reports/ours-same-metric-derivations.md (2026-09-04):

# How every "Ours, same metric" cell of the poster's related-work table was derived

Written 2026-09-04. Companion to `poster.tex` (third column, "Related work"), to
`related-work-table.tex` (the fit harness holding the same block) and to
`comparison-review/review.pdf` (the review that judged whether each cell really matches its row).

The column exists because manuscript Table 2 put our one-directional map distance in the same column
as a signed bias, a class-value RMSE and a per-press centre error, none of which measure the same
thing. Each cell here is **our own predictions re-scored under the definition the baseline in that
row uses**, so that the two numbers beside each other are the same quantity.

## Where the numbers come from

Nothing in this column comes from a new training run. Two saved artefacts feed everything:

| artefact | produced by | what it holds |
|---|---|---|
| `analysis/results/frame_space_predictions_<config>.npz` | `analysis/scripts/frame_space_predictions.py` | per-marker sigmoid probabilities, ground-truth labels and 1920x1080 pixel positions for every scored (central) video frame of each test set, from the best-of-five model instance of each configuration |
| `analysis/results/comparable_metrics.json` | `analysis/scripts/comparable_metrics.py` | every frame-space quantity below, derived from the `.npz` files |
| `analysis/results/symmetric_distances.json` | `analysis/scripts/symmetric_distances.py` | map-space distances and foreground IoU, from the `prediction.png` / `ground_truth.png` of the manuscript's own vessel-map runs |

Conventions used throughout, identical to the manuscript's Table 4:

* **Threshold 0.5** on the per-marker sigmoid, in frame space.
* **Geometry** 55 px = 2 mm (`main.py::PX_TO_MM`), so 1 px = 0.036364 mm; map space is 1 px = 1 mm.
* **Scoring unit** in frame space is one central video frame of a five-frame clip. A *frame* is what
  a baseline would call a *press* or a *clip*; frames inside one trial are not independent, so the
  effective n is smaller than the frame count. Counts: 675 / 120 / 219 / 120 frames for
  Sim->Sim / Sim->Silicone / Sim->Meat / Meat->Silicone, of which 296 / 94 / 129 / 94 contain a
  vessel.
* **Centroid statistics** drop frames in which the model predicts nothing (no centroid exists):
  n = 296 / 92 / 113 / 94, and the lateral ones additionally drop frames whose labelled markers have
  no well-defined principal axis (n = 296 / 92 / 105 / 94).
* Every cell names the transfer it comes from. Where a cell quotes one transfer only it is
  **Sim->Silicone**, which `comparison-review/review.pdf` Sec. 4 checks is the worst or second-worst
  of the four on that metric, i.e. not a cherry-pick.

## Cell by cell

### MiniTac [1] --- "present / absent, per press" --- ours: 100 % Sim->Sim, 93 % Sim->Silicone

*Their definition.* Per-press binary accuracy of a linear SVM over a test split of roughly 56
presses with the two classes deliberately balanced.

*Our derivation.* `per_press_accuracy` in `comparable_metrics.json`. Per frame, a vessel-present
frame counts as correct if **any** marker passes 0.5, and a vessel-free frame counts as correct if
**none** does; the two are pooled over all frames of the test set:

```
per_press_accuracy = (#present frames with a detection + #vessel-free frames with none) / #frames
Sim->Sim        675/675 = 1.000  -> 100 %
Sim->Silicone   112/120 = 0.933  ->  93 %
```

*Caveat to state at the poster.* Our classes are unbalanced the other way (94 present against 26
vessel-free on Silicone), so the 93 % is dominated by the present class, and the 100 % is an
**in-domain** test.

### DIGIT Pinki [2] --- "hardness class, per clip; silicone, phantom" --- ours: 78 % Meat->Silicone

*Their definition.* Per-clip accuracy of a VideoMAE head over 11 hardness classes (silicone
swatches, 98 %) and 6 classes (phantom prostate, 100 %), on splits taken inside each palpation
video.

*Our derivation.* We have no multi-class analogue, so the cell reuses the same
`per_press_accuracy`, quoted on Meat->Silicone: 94/120 = 0.783 -> 78 %.

*Caveat.* A two-class rate is easier than an eleven-class one, so this cell **understates** the gap
in the baseline's favour. It is quoted on Meat->Silicone because that is the real-data-trained
model, the closest counterpart to a model trained on the material it is tested on. The full set is
100 / 93 / 71 / 78 % --- have the unquoted Sim->Meat value, 71 %, ready.

### Bewley et al. [3] --- "lump found when present, at 8 N" --- ours: 98 % Sim->Silicone, 88 % Sim->Meat

*Their definition.* The proportion of trials in which a lump's presence was detected at 8 N, read
off their Fig. 13. It is a *when-present* rate, not a balanced accuracy.

*Our derivation.* `detection_rate`: the fraction of **vessel-present** frames in which at least one
marker passes 0.5. Sim->Silicone 92/94 = 0.979 -> 98 %; Sim->Meat 113/129 = 0.876 -> 88 %.

*Caveat --- volunteer this one unprompted.* The other half of the confusion matrix is on no cell:
`false_alarm_rate`, the fraction of **vessel-free** frames in which the model fires anyway, is
0 % Sim->Sim, **23 % Sim->Silicone, 52 % Sim->Meat and 100 % Meat->Silicone**. A high when-present
rate is cheap for a detector that fires often.

### Yan & Pan [7] --- "estimated -> true tumour centroid" --- ours: 3.7 +/- 2.5 mm, Sim->Silicone

*Their definition.* The centroid clustering error: the Euclidean distance between the estimated and
the true tumour centroid, 1.4--4.7 mm over three tumours after 30 Bayesian-optimisation iterations.

*Our derivation.* `centre_mae_mm` +/- `centre_sd_mm`. Per frame, the 2-D Euclidean distance between
the centroid of the markers the model calls vessel and the centroid of the truly-vessel markers,
converted to mm, then averaged over the frames that have a prediction:
Sim->Silicone 3.690 +/- 2.472 mm over n = 92 -> **3.7 +/- 2.5 mm**. The other transfers are
1.4 / 3.7 / 3.4 / 2.7 mm, so Sim->Silicone is the **worst** of the four.

### Raina et al. [8] --- "reconstructed -> CT centreline" --- ours: 1.2 mm Sim->Silicone, 5.5 mm Sim->Meat

*Their definition.* The k-nearest-neighbour distance between the ultrasound-reconstructed vein and
artery centrelines and the CT ground-truth centrelines of the phantom, ICP-aligned; mean 2.15 mm.

*Our derivation.* `map.one_directional_mm` in `symmetric_distances.json` --- the mean distance from
each **predicted** top-view-map vessel pixel to the nearest **true** vessel pixel, 1 px = 1 mm:
Sim->Silicone 1.21 -> **1.2 mm**, Sim->Meat 5.49 -> **5.5 mm**.

*Caveat --- the weakest match in the column, so say it first.* Theirs is a 3-D centreline-to-
centreline distance against a CT ground truth; ours is a 2-D distance from a predicted pixel to the
nearest pixel of a labelled **band**, at a threshold chosen on the test set. A band is wider than a
centreline, so our figure is structurally the smaller one. It is in the table because it is the
closest published definition to ours anywhere in the comparison, not because the two are
interchangeable.

### 3D CNN [6] --- "centre within tolerance, per video" --- ours: 78 % at 5 mm, 47 % at 3 mm, Sim->Silicone

*Their definition.* The proportion of the 100 validation **videos** whose predicted **"Guan" point**
--- the TCM pulse-taking position on the radial artery, a single pixel marked by a physician --- falls
within 50 px of that label, at 1024x544 px; the paper gives no px-to-mm scale, so their tolerance
cannot be converted. It is a regressed landmark point, not a centroid of a segmentation and not a
centreline (verified in the paper on 2026-09-04).

*Our derivation.* `hit_rate`, the fraction of vessel-bearing **frames** whose predicted centroid
lies within tau mm of the true centroid, swept over tau. Sim->Silicone: tau = 5 mm 0.783 -> 78 %,
tau = 3 mm 0.467 -> 47 % (the full sweep is 1 / 10 / 27 / 47 / 78 % at 0.5 / 1 / 2 / 3 / 5 mm).

*Caveat.* Their unit is a video, ours a frame, and the two tolerances are not comparable because
theirs has no metric scale. Two values are printed rather than one so the reader sees how steeply
the rate falls with the tolerance.

### Beasley et al. [4] --- "signed lateral bias of artery position" --- ours: +0.4 +/- 2.7 mm, Sim->Silicone

*Their definition.* A **signed** across-artery position error, +1.3 mm with an SD of 7.6 mm over 33
points --- a bias, not an accuracy: it cancels errors on opposite sides of the vessel.

*Our derivation.* `centre_lat_signed_mean_mm` +/- `centre_lat_signed_sd_mm`. The centroid offset of
the frame is projected onto the **normal of the vessel**, and the vessel's direction is taken as the
principal axis of that frame's labelled markers, so the lateral axis follows the vessel instead of
assuming an image axis. Sim->Silicone +0.410 +/- 2.708 mm -> **+0.4 +/- 2.7 mm**.

*Why this is not the image x axis (a correction made on 2026-09-03).* The cell used to read
-0.1 +/- 3.1 mm, the signed offset along image x. In Sim and Silicone a frame's labelled band spans
about 21 mm in x against 4--8 mm in y (principal axis 6--11 degrees from x), so image x is the
**along**-vessel axis --- the opposite of what Beasley measures; on Meat it is the other way round.
An axis-aligned cross-check of the corrected quantity gives +0.36 +/- 3.13 mm, so the correction
does not hinge on the principal-axis estimate. See `comparison-review/review.pdf` Sec. 2.7.

### Hampson et al. [5] --- "absolute lateral error of centre, in range" --- ours: 1.9 +/- 2.0 mm, Sim->Silicone

*Their definition.* The **absolute** lateral error of the estimated artery centre per press,
0.58 +/- 0.25 mm, holding only while the artery is within range of the tactile array; out of range
their Fig. 4 shows roughly 2--8 mm. The paper does not say whether the +/- is an SD, an SE or a
range.

*Our derivation.* `centre_lat_abs_mean_mm` +/- `centre_lat_abs_sd_mm`: the unsigned value of the
same across-vessel projection as the Beasley cell. Sim->Silicone 1.880 +/- 1.983 mm ->
**1.9 +/- 2.0 mm** (median 1.41 mm). Previously 3.7 +/- 2.5 mm, which was the full 2-D distance and
therefore included the along-vessel component that Hampson does not measure.

*Reading.* This is the row we lose most clearly: 1.9 mm against 0.58 mm, about three times worse,
and their number is the in-range best case while ours is over every frame.

### Ours (last row) --- "predicted pixel -> nearest true pixel" --- 1.1, 1.2, 5.5, 1.3 mm

Not a recomputation: this is the manuscript's own Table 4 quantity, the mean distance from each
predicted vessel pixel of the top-view map to the nearest true vessel pixel, for
Sim->Sim / Sim->Silicone / Sim->Meat / Meat->Silicone. `symmetric_distances.py` recomputes it from
the manuscript's own map runs and asserts it against Table 4: 1.05 / 1.21 / 5.49 / 1.31 mm. It is
the same definition the segmentation bar panels now print, so the two Results blocks agree.

## Reproducing the column

```bash
# frame-space cells (everything except the Raina cell and the Ours row)
python analysis/scripts/comparable_metrics.py
# map-space cells (Raina cell, Ours row) and the segmentation bar panels
python analysis/scripts/symmetric_distances.py   # needs REPO on disk
python analysis/scripts/segmentation_bars.py
```

`comparable_metrics.py` reads only the saved `.npz` predictions, so it runs in seconds and needs no
GPU, no simulator and no model. `symmetric_distances.py` additionally reads the vessel-map PNGs from
the code repository.

## What no cell in the column shows

Ranked as `comparison-review/review.pdf` Sec. 5 ranks them, all presenter material:

1. The **false-alarm rates** behind the three detection cells (23 / 52 / 100 %, above).
2. **n and independence** --- no cell carries an n, and frames within one trial are not independent
   (Silicone is ten annotated videos, Meat ten trials).
3. **Two operating points in one table** --- frame-space cells at threshold 0.5, the map-space cells
   at a threshold chosen on the test data.
4. The **Meat recall ceiling**: a perfectly localised model can recover at most 53 % of the shipped
   Meat map truth, so Meat recalls are not comparable with Silicone ones. Only the Sim->Meat
   *distance* is printed, which the ceiling does not inflate.
5. The **reverse-direction distance** (truth to prediction), 0.03 / 2.24 / 0.69 / 0.18 mm in frame
   space and an ASSD of 0.75 / 1.49 / 4.36 / 1.50 mm in map space.

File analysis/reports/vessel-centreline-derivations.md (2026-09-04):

# How the blood-vessel centreline is computed in this project

*2026-09-04. Companion to `analysis/reports/ours-same-metric-derivations.md`, which derives the
"Ours, same metric" column of the poster's comparison table. This note answers the four
questions asked about the centreline behind those numbers, and documents the per-vessel
overlays generated for every data point that feeds them.*

---

## Short answers

| Question | Answer |
|---|---|
| **Is the centreline aligned with the image x- or y-axis, or can it be skew?** | Skew. It is a free principal-axis (PCA/SVD) direction fitted to the vessel-labelled markers of the frame, never an assumed image axis. On Sim→Sim it sits **10.5°** off image x in every single frame; on Silicone its median offset from the nearest image axis is **4.4°** and reaches **43°**; on Meat it runs along image y (median **1.0°** off). |
| **What happens when a frame contains several vessels?** | They are **merged**, not separated and not discarded. One centroid and one principal axis are taken over the *union* of the vessel-labelled markers, so two vessels become a single fictitious "mean vessel". 26 / 51 / 26 / 51 frames (Sim→Sim / Sim→Silicone / Sim→Meat / Meat→Silicone) contain more than one vessel and are treated this way. |
| **Frame space, top-view space, or both?** | **Frame space only.** No top-view metric uses a centreline, a centroid or an axis: `symmetric_distances.py` works purely with a Euclidean distance transform of the two masks. |
| **Is there a "centreline" object in the code at all?** | Only one, and it is not an estimate: the simulator's own vein geometry, written out as `ground_truth_centreline_reference.png` for the Sim→Sim map. It is a reference picture and feeds no metric. |

The per-vessel centrelines requested — one magenta line per ground-truth vessel, one orange
line per predicted vessel, index-matched — **did not exist before this note**. They are new,
built for visualisation and for the sensitivity check in §6, and they do not change any number
on the poster.

---

## 1. What the published metrics actually compute

### 1.1 Frame space — one merged axis per frame

Everything centreline-flavoured on the poster comes from `analysis/scripts/comparable_metrics.py`:

```python
def centroid(pos, mask):                                    # comparable_metrics.py:54
    return pos[mask].mean(axis=0) if mask.any() else None

def lateral_normal(points):                                 # comparable_metrics.py:59
    if len(points) < 3:
        return None
    axis = np.linalg.svd(points - points.mean(axis=0), full_matrices=False)[2][0]
    n = np.array([-axis[1], axis[0]])
    return n if n[1] >= 0 else -n
```

and, per frame (`per_frame`, lines 73–89):

```python
t = centroid(pos[i], labels[i])                 # centroid of ALL vessel-labelled markers
p = centroid(pos[i], pred[i])                   # centroid of ALL predicted markers
n = lateral_normal(pos[i][labels[i]])           # normal of ONE axis through ALL of them
lat = (p - t) @ n * MM_PER_PX                   # the signed lateral error
```

So the "centreline" is implicit: it is the line through the ground-truth centroid `t` along the
first principal component of the vessel-labelled markers. Three consequences follow directly
from those five lines:

* **it is skew by construction** — `axis` is whatever direction the SVD returns;
* **it is one line per frame, not one per vessel** — the mask `labels[i]` is not split;
* **it exists only where at least 3 markers are labelled** — `lateral_normal` returns `None`
  below that, and the frame drops out of the lateral aggregates (this is the only discarding
  that happens, and it is about marker count, not vessel count).

Which poster cells depend on it: the **Beasley** row (signed lateral bias, `centre_lat_signed_*`)
and the **Hampson** row (absolute lateral error, `centre_lat_abs_*`). The **Yan & Pan** row
(`centre_mae_mm`) uses the two centroids only — no axis at all. The **Raina** row and the
segmentation-statistics figure use the top-view distance, which is §1.2.

### 1.2 Top-view space — no centreline anywhere

`analysis/scripts/symmetric_distances.py::map_space` scores the two masks pixelwise:

```python
to_gt_pos = ndimage.distance_transform_edt(~gt)   # distance to the nearest true vessel pixel
d_pos = to_gt_pos[pred]                           # for every predicted vessel pixel
```

That is the manuscript's one-directional distance. No clustering, no centroid, no principal
axis, no vessel identity. The number a reader might read as "distance to the centreline" is a
distance to the nearest *ground-truth vessel pixel* — the whole labelled band, not its middle.

### 1.3 The one literal centreline in the code base

`difftactile/object_model/vein.py:32` builds the simulated vein as a chain of particles along a
known straight centreline, and `difftactile/data_analysis/experiment/vessel_map.py:700–703,
853–860` projects it into map pixels and saves it as
`ground_truth_centreline_reference.png`, **only for vessel-present simulated trajectories**
(the comment there is explicit: for a vessel-absent trial the vein is not physically present, so
a reference line would mislead). It is ground-truth world geometry, not an estimate from
predictions, and no metric reads it back.

---

## 2. Evidence for the "skew" answer

Angle of the fitted axis, over every frame with ≥3 labelled markers:

| Config | n frames | median axis angle | 5–95 % | median offset from the nearest image axis | max offset | frames > 5° off an axis |
|---|---|---|---|---|---|---|
| Sim→Sim | 296 | 10.5° | 9.5–13.0° | **10.5°** | 13.6° | **100 %** |
| Sim→Silicone | 94 | 152.7° | 1.0–178.7° | 4.4° | **43.2°** | 46 % |
| Sim→Meat | 112 | 89.8° | 83.3–96.4° | 1.0° | 28.3° | 13 % |
| Meat→Silicone | 94 | 152.7° | 1.0–178.7° | 4.4° | 43.2° | 46 % |

Sim→Sim is the clearest case: the vein is consistently tilted ~10° from image x, and an
axis-aligned assumption would have been wrong in every frame. On Silicone the wide spread is
mostly the merged-vessel effect of §1.1 — when a frame holds two vessels the merged axis can
swing far from either of them (§6).

Silicone and Meat→Silicone are identical rows because both models are evaluated on the same
94 silicone frames; the axis depends only on the *ground truth*, not on the model.

---

## 3. The new per-vessel overlays

`analysis/scripts/centreline_overlays.py` produces the requested pictures. Method, per data point:

1. **Split into vessels.** DBSCAN on the vessel elements.
   *Frame space:* `eps = 1.45 ×` the dataset's median inter-marker spacing (2.62–2.84 mm for a
   1.81–1.96 mm spacing), `min_samples = 1`. At 1.45 × spacing a marker links only to its
   immediate hexagonal neighbours, so two vessels separated by one clear marker gap stay apart.
   *Top-view space:* `eps = 3 mm`, `min_samples = 3`, clusters below 5 px ignored.
2. **Fit one centreline per vessel** — total least squares: the line through the cluster centroid
   along its first principal component, drawn between the cluster's extreme projections.
3. **Match ground truth to prediction** — Hungarian assignment on centroid distance, rejecting
   pairs farther apart than 10 mm (frame) / 20 mm (map).
4. **Index and draw.** Ground-truth vessels are numbered 0, 1, 2 … across the common vessel
   direction (down the image for the silicone sweeps, left-to-right for the meat straws); a
   matched prediction carries its partner's number. **Magenta k and orange k are a pair; an index
   that appears in only one colour is unmatched** — a missed vessel or a spurious blob.
   Markers/pixels keep the project's confusion colours (TP green, FN red, FP blue, TN grey).

Two properties of that recipe are worth knowing when reading the pictures. A cluster of a
single element has no direction, so it is drawn as an `x` with its index rather than a line —
in frame space an isolated labelled marker is counted as a vessel of its own rather than
silently dropped, which is why some frames report three "vessels" for one real one. And the
matching is on **centroid distance only**; where a long predicted band sits beside several short
ground-truth clusters, it is assigned to whichever centroid is nearest, which is not always the
cluster a person would pair it with by eye (`frame_space/Sim-to-Meat/frame_0093.png` is an
example). Both are visualisation choices and neither touches a published number.

### Three variants of every figure

A centreline and a centroid are different objects — the centreline is the fitted *axis* of a
vessel, the centroid its *centre of mass*, a single point — so each data point is drawn three
ways rather than one:

| variant | what it draws |
|---|---|
| `centreline/` | one straight centreline per vessel, indexed |
| `centroid/` | one centroid dot per vessel, indexed |
| `both/` | the two together; the centroid always lies on its own centreline |

The indices are the same in all three, so a vessel can be followed from one variant to another,
and in `both/` a vessel's number is printed twice — once at the end of its line, once beside its
centroid. Frame-space figures additionally show, in a lighter weight, the geometry the
*published* metric uses, and that follows the variant too: the merged principal axis (dashed
magenta) and its normal (dashed grey) appear in `centreline/` and `both/`, the merged
ground-truth centroid (magenta star) and merged predicted centroid (orange star) in `centroid/`
and `both/`. The offset between those two stars, projected onto the dashed grey axis, *is* the
lateral error the Beasley and Hampson cells report. The title states whether that frame entered
the lateral aggregate.

### Coverage

One image per data point that feeds a centreline metric — every vessel-bearing frame, and every
top-view trial map:

| Config | frame-space overlays | of which in the lateral aggregate | top-view overlays |
|---|---|---|---|
| Sim→Sim | 296 | 296 | 1 (whole map) |
| Sim→Silicone | 94 | 92 | 1 (whole phantom) |
| Sim→Meat | 129 | 105 | 10 (one per trial) |
| Meat→Silicone | 94 | 94 | 1 (whole phantom) |
| **total** | **613** | **587** | **13** |

Each of those 626 data points is drawn in the three variants above, so the run holds
1839 frame-space and 39 top-view images.

The in-aggregate counts reproduce `n_lat_frames` in `analysis/results/comparable_metrics.json` exactly
(296 / 92 / 105 / 94), so the picture set and the printed numbers cover the same data points.

### Where the images are

```
analysis/centrelines/<YYYYmmdd-HHMMSS>/     timestamped, so runs never overwrite each other
    README.md            what the run is and how to read the pictures
    params.json          every threshold, eps, gate and source path
    vessels.json         per-data-point vessel counts, matches, centre and lateral errors
    frame_space/<Config>/<variant>/frame_<i>.png   one per vessel-bearing test frame
    top_view/<Config>/<variant>/<map>.png          one per test-set trial map
    contact_sheets/<space>_<Config>_<variant>.png  thumbnail grids for a quick scan
                                                   <variant> = centreline | centroid | both
analysis/centrelines/latest -> <YYYYmmdd-HHMMSS>
```

Current run: `analysis/centrelines/20260904-115206` (121 MB, 1902 images). The bulk frame-space
images and the contact sheets are git-ignored — they are regenerable artefacts; the 39 top-view
maps, the manifests, the script and this report are what the repo carries.

---

## 4. Validation of the clustering

The top-view vessel counts recovered by DBSCAN are checked against what was physically in each
trial, which is recorded in the trial directory names:

| Config / trial | vessels recovered | physically present |
|---|---|---|
| Sim→Sim, whole map | 1 | 1 simulated vein |
| Sim→Silicone, whole map | **10** | "silicone phantom, **ten sweeps**, 180 × 100 mm" (`run.json`) |
| Meat→Silicone, whole map | **10** | same phantom map |
| Sim→Meat trials 01–07 | 1 each | `1-metal-straw-…`, `1-silicone-straw-…` |
| Sim→Meat trial 08 | **2** | `2-metal-straws-beneath-2-steaks` |
| Sim→Meat trial 09 | **3** | `3-metal-straws-beneath-2-steaks` |
| Sim→Meat trial 10 | **0** | `no-straw` |

Every count is right, including the empty control, so the operating point is not tuned to a
single case.

---

## 5. The silicone map: why there is no 10-way split and 5-way stitch

The requested route was: treat the ten silicone slides as ten small maps, then stitch five of
them into a whole-phantom map with re-indexed captions. That is not possible from the saved
artefacts, and it turns out not to be needed.

* The silicone map the manuscript's run saved **is already the stitched whole-phantom map** —
  one 100 × 180 mm image described in `run.json` as *"silicone phantom, ten sweeps,
  180 × 100 mm workspace"*. There are no ten sub-maps on disk; `sim-to-silicone_gt-video/…`
  contains a single `ground_truth.png` / `prediction.png` pair, unlike `sim-to-meat_gt-video/…`,
  which does have ten trial sub-directories.
* `run.json` carries **no per-sweep provenance** — no per-source pixel mask, no sweep index.
  (`ground_truth_sources_overlay.png` is video-derived vs photo-derived ground truth, not
  per-sweep.) Splitting the combined map by which sweep wrote each pixel would mean re-running
  the map builder over the ten videos, which is a heavyweight job and has not been run.
* **The split was only a means to an end**, and the end is reached directly: clustering the
  whole-phantom map recovers exactly the ten sweeps as ten separate vessels (§4), each with its
  own centreline and its own index, 0–9, on one big map. That is the artefact the stitch was
  meant to produce, without the intermediate step.

If you want the genuine ten sub-maps as well — separately built, then stitched — say so and I
will re-run the map builder; it needs your permission because it is not a last-minute metric
recomputation.

---

## 6. What the merge costs (sensitivity check)

Since the per-vessel decomposition now exists, the lateral error can be recomputed per matched
vessel pair instead of per merged frame. Nothing on the poster changes — this is a check, not a
replacement:

| Config | published (merged), signed | per-vessel, signed | published, absolute | per-vessel, absolute | per-vessel axis vs merged axis (median / 95th) |
|---|---|---|---|---|---|
| Sim→Sim | +0.02 ± 1.55 mm (n=296) | −0.04 ± 1.62 mm (n=296) | 1.18 ± 1.00 mm | 1.22 ± 1.06 mm | 0.0° / 12.1° |
| **Sim→Silicone** | **+0.41 ± 2.71 mm** (n=92) | −0.09 ± 1.78 mm (n=131) | **1.88 ± 1.98 mm** | 1.17 ± 1.34 mm | 9.0° / 89.1° |
| Sim→Meat | −0.41 ± 3.59 mm (n=105) | −0.37 ± 2.87 mm (n=105) | 2.74 ± 2.34 mm | 2.23 ± 1.83 mm | 0.0° / 27.6° |
| Meat→Silicone | +0.89 ± 2.94 mm (n=94) | +0.57 ± 3.90 mm (n=108) | 2.16 ± 2.17 mm | 3.04 ± 2.49 mm | 7.2° / 89.0° |

Read: on **Sim→Silicone**, the configuration the poster's Beasley and Hampson cells report, the
merge makes our number **worse**, not better — per vessel the absolute lateral error is
1.17 mm against the printed 1.88 mm, and the signed bias shrinks from +0.41 to −0.09 mm. The
printed cells are therefore the conservative choice, which is the right way round for a claim
against a baseline. The 95th-percentile axis deviations near 90° on the two silicone rows are
the two-vessel frames: when a frame holds two parallel sweeps whose union is wider than it is
long, the merged principal axis flips to run *across* the vessels rather than along them, and
the merged lateral error picks up the along-vessel offset instead. Per vessel that cannot
happen.

The single-vessel-dominated configs (Sim→Sim, Sim→Meat) agree to within 0.05 mm signed, which is
the expected result and a sanity check on the clustering.

---

## 7. Reproduction

```bash

# the overlays and their manifests (about 75 s, writes a new timestamped folder)
python analysis/scripts/centreline_overlays.py

# the published numbers this note refers to
python analysis/scripts/comparable_metrics.py        # centre / lateral / hit-rate aggregates
python analysis/scripts/symmetric_distances.py       # top-view distances and FG IoU
```

`analysis/scripts/centreline_overlays.py --limit N` renders only the first N frames per config, for a
quick look. Both parameters and source paths are recorded in each run's `params.json`.

---

## 8. Summary

The project has never estimated a per-vessel centreline. It fits **one skew principal axis per
video frame, over all vessel-labelled markers at once**, and uses its normal to split the
centroid offset into a lateral component — that, and nothing more, is what the Beasley and
Hampson cells report. Top-view space uses no centreline at all. Multiple vessels in a frame are
merged rather than separated or discarded, which on the silicone configuration makes the printed
lateral error larger than a per-vessel treatment would. The new overlays make all of this
visible data point by data point, with the centrelines and the centroids drawn separately and
together, and the ten silicone sweeps come out of the whole-phantom map
as ten separately indexed vessels without needing the split-and-stitch route.

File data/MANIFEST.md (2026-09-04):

# Zenodo data bundle — contents and rationale

This document describes the archive published on Zenodo alongside this
repository, and — just as importantly — what is **deliberately left out**.

## Guiding principle

**Anything the repository's own scripts can regenerate is excluded.** The bundle
carries only artifacts that a user cannot produce themselves, either because
they are recordings of physical experiments or because regenerating them takes
impractically long.

Two kinds of exception are made:

1. **Generable but expensive.** The simulated training dataset (`script_main`,
   ~5 h 30 m of GPU time for the shipped 500-trajectory configuration), the
   published five-seed sweep of trained models, and the domain-adaptation BO
   run are all reproducible from the repository, but a user who only wants to
   verify the published results should not have to pay hours of GPU time.
   They are treated as non-generable and shipped.
2. **The manuscript's own figures and tables** (`manuscript_artifacts/`). These
   are cheap to regenerate and are the *only* things shipped purely for
   convenience: they are the exact figures and result tables the manuscript
   presents, so a reader can check any number against the archive without
   running anything. They are staged under their own directory rather than at
   their working-tree paths, so a restore never overwrites what a user's own
   runs have produced.

## Bundle paths vs. the currently published archive

The bundle must be the **post-rename** one: its paths, and the names stored
*inside* its pickles and checkpoints, match the current code exactly. The
compatibility shims that let a pre-rename archive restore into this layout were
removed once the rebuilt bundle became the published artifact; see the repository
history if you ever need to read a pre-rename bundle again.

> If a restore reports paths under `endgame/`, `iros_training_data/` or
> `saved_models_{iros,icra}/`, you have an outdated archive. Re-download it from
> the DOI rather than renaming files by hand — the old bundle also carries stale
> names inside its pickles, which a path rename cannot reach.

## What IS in the bundle

| Path (after restore) | Size | Why it cannot be regenerated |
|---|---:|---|
| `difftactile/output/training_data/pickle_20260814_191137_reordered_dense/` | ~250 MB | 500 simulated trajectories (250 with / 250 without the vessel), collected at the post-Bayesian-optimisation simulator parameters. Generable via `script_main` (~5 h 30 m GPU); shipped for convenience. |
| `difftactile/manual_or_experimental_data/silicone_training_data/20250901-131547_dense/` | ~684 KB | Real **silicone** phantom trials, fully preprocessed. Physical recording. |
| `difftactile/manual_or_experimental_data/meat_training_data/clean/` | ~480 KB | Real **meat** phantom trials, fully preprocessed (10 trials × 2 `.npz`). Physical recording. Directories are named `<description>-<timestamp>`, e.g. `2-metal-straws-beneath-2-steaks-20260228-235749`, so the trial's condition is readable without cross-referencing `meat_experiment_spec.md`. |
| `difftactile/manual_or_experimental_data/meat_training_data/clean/*/frames.mp4` | ~22 MB | The 26 camera frames per meat trial that preprocessing kept, H.264 CRF 26 (~2.3 MB each). Frame *i* corresponds 1:1 with row *i* of `marker_labels.npz`, so the annotation viewer can draw the ground-truth labels over the real meat images (paper Fig. `annotation-line`(d)). Cut down from the 1.6 GB raw recordings by `script_make_meat_clean_videos`; the raw videos themselves are a physical recording and are not shipped. |
| `saved_models_sim/final_segmentation_model_gnn_sim.pt` | ~4.2 MB | The simulation-trained (large) GNN checkpoint behind Sim→Sim, Sim→Silicone and Sim→Meat. It is the **best-of-five** seed instance (highest AP on Silicone) of the published sweep below. |
| `saved_models_meat/final_segmentation_model_gnn_meat.pt` | ~300 KB | The meat-trained (compact) GNN checkpoint behind Meat→Silicone; the best-of-five instance of the sweep. |
| `saved_models_sweeps/20260815-194045/` | ~70 MB | **The published five-seed sweep**: for each of the four configurations, five seeds (0–4), each with its checkpoint, its test-loader pickle (normalisation statistics — the two must be used together) and its per-seed score arrays; `sweep.json` records every metric and which seed is best-of-five. Every mean ± std in the manuscript, and the mean ROC/PR curves, come from here. Trained with a 5-frame temporal window (`gnn.clip_len` 5) on the regenerated simulated dataset. Retrainable in ~20 min of GPU time (`./docker/score_all_scenarios.sh --seeds 5`), shipped for convenience and because it is the artifact the results rest on. |
| `saved_models_legacy/{sim,meat}/` | ~4.6 MB | **Legacy models** (pre-2026-08-15): the original checkpoints + pickles from the accepted version. Kept only because they produced the accepted manuscript's bird's-eye map figure and localisation table; **not used for any main result**. Cannot be retrained (previous, unseeded simulated dataset; 7-frame window). See `saved_models_legacy/README.md`. |
| `difftactile/output/vessel_map_sim/{raw,raw_reordered_dense}/` | ~1.5 MB | The one simulated vein-present slide, with per-frame sensor poses (`T_BA`) and the vein's world centreline, from which the Sim→Sim bird's-eye map is drawn. Regenerable in ~2 min with a GPU (`docker/vessel_map_sim_trajectory.sh`, seed 2026); shipped so the map needs no simulator. |
| `difftactile/output/vessel_map_sim/test_trajectories/` | ~4 MB | The ten held-out simulated trajectories shown in the project page's Sim→Sim prediction video (7 vessel-present + 3 vessel-absent, fixed-seed draw, interleaved), each the **published** markers/labels plus the sensor poses re-simulated by replaying the dataset's seed (`docker/vessel_map_sim_test_trajectories.sh`, ~15 min GPU, verified against the published files); `selection.json` fixes the order. Behind the page's ten Sim→Sim bird's-eye maps (`docker/website_vessel_maps.sh`). |
| `difftactile/output/test_loader_gnn_sim.pickle` | ~60 KB | Normalisation statistics that the simulation-trained checkpoint was trained with; needed to evaluate it correctly. |
| `difftactile/output/test_loader_gnn_meat.pickle` | ~4 KB | As above, for the meat-trained checkpoint. |
| `difftactile/output/` sensor-geometry set (16 files) | ~5.5 MB | Sensor mesh, marker layout and graph connectivity: `base-graph-connectivity.npz`, `marker_locations_ordered.npz`, `init-marker-positions.{npz,pkl}`, `gmsh_mesh_{vitactip,vein}.pkl`, `vitactip_mesh.npz`, `edge_lengths.pkl`, `tactile_sensor.f2v.pkl`, `phantom_points.npz`, `vein_points.npz`, `is_fixed_layer.npz`, `grid_node_v0_mask.npz`, `initial_vertex_positions_undeformed.pkl`, `vitactip_points_E.pkl`. Regenerable (Gmsh + marker detection) but tiny, fixed, and required before the simulator will start. |
| `difftactile/output/marker_tracker/domain-adaptation-vascular-markers/` | ~1.3 MB | System-identification marker tracks (`traj_0..3_out.pkl`), loaded at simulator start-up to align the contact model against the real sensor. |
| `manuscript_artifacts/` → restored to `difftactile/output/manuscript_artifacts/` | ~8 MB | **The manuscript's figures and tables, as published — the one "generable but included" exception.** `figures/`: the Fig. 4 alignment panels (`alignment_{press,twist_z,twist_x,slide,all}.png`) and the Fig. 6 mean PR curves plus their ROC twins (`mean_{pr,roc}_curve_<config>.pdf`, five-seed mean ± 1 std) and the one shared legend and x-axis label set once for the row (`curve_legend.pdf`, `xlabel_recall.pdf`). `tables/`: `AUROC_RESULTS.md` (per-scenario metrics of the published checkpoints), `sweep.json` (every per-seed metric behind Fig. 6 and the best-of-five choice), `CLIP_LEN_ABLATION.md` (Table 3), `FRAME_SPACE_METRICS.md` (Table 4, upper half), `alignment_validation.json` (the MAEs beside Fig. 4). `vessel_maps/<train>-to-<test>_gt-<source>/`: the latest `vessel_map_all.sh` run of each of the six map configurations (Fig. 7, Table 4 lower half) with `confusion_rNN.{png,pdf}`, `metrics_by_radius.md`, `report.md`, `run.json`. `manuscript_artifacts/README.md` maps every file to its manuscript figure/table and to the repository path and script it came from. |
| `analysis/results/frame_space_predictions_<config>.npz` | ~1.5 MB | Per-marker probability, label, pixel position, trial and frame index of every central test frame, for all four published models — stage 1 of `docker/reproduce_analysis.sh`. Regenerable in about a minute, but **only on a GPU**, and every other stage of the poster's analysis reads them; shipping them is what lets a CPU-only machine rebuild every poster figure and number. They are gitignored (`*.npz`), so the bundle is the only place they exist outside a run. Because they are regenerable, `restore_data.sh --verify` reports them as `ABSENT  … (regenerable)` rather than failing, so a bundle downloaded before they were added still verifies. |
| `difftactile/output/domain_adaptation_published/` | ~12 MB | The published domain-adaptation BO run behind the adopted simulator parameters. `joint_bo/` is the 10-iteration joint search over sensor Young's modulus and sensor↔vein contact stiffness: `bo_joint_results.json` (every iteration, both reward terms and the best configuration), `iteration_log.csv` (the same, written live one line per iteration), `final_joint_validation.json` (all four trajectories at the winning configuration), the `da_overlay_*.png` alignment figures and the per-iteration `vein_iterNNN_overlay_slide.png`. Also holds the manuscript's white-background alignment panels (`alignment_{press,twist_z,twist_x,slide,all}.png`, drawn by `docker/alignment_figures.sh` at the adopted parameters), the `markers_*.npz` marker-position caches behind them (so the figures can be restyled without re-simulating) and `alignment_validation.json` with the per-trajectory MAEs. |

**Total: roughly 375 MB uncompressed / ~275 MB as a `.tar.gz`**, dominated by the
simulated dataset, the five-seed sweep and the meat camera frames.

Note on the poster's analysis (`analysis/`): only the four `.npz` above are shipped.
Everything else that tree produces — the metric JSON, the figures and the Markdown
reports — is regenerated from them in about a minute by `./docker/reproduce_analysis.sh`
and is tracked in git, so shipping it again would duplicate the repository. The published
top-view map runs the analysis also reads are already in the bundle, under
`manuscript_artifacts/vessel_maps/`.

Note the BO runs' `snapshots/` subdirectories are **excluded** — ~16 MB of rendered
PNGs per run, regenerable from the recorded parameters, and a debugging aid rather
than an artifact. The JSON histories and the overlay figures are what the reported
results rest on.

## What is NOT in the bundle (and why)

| Excluded | Size in the raw archive | Reason |
|---|---:|---|
| `meat_training_data/raw/` | 1.6 GB | Full-rate `.avi` recordings (429 frames each) + pose `.npz`. Only needed to re-run preprocessing from scratch; `clean/` is the product, and the 26 frames per trial that preprocessing actually keeps now ship as `clean/*/frames.mp4` at 3% of the size. |
| `meat_training_data/intermediate/` | 250 MB | Intermediate preprocessing stages; reproducible from `raw/`. |
| `meat_training_data/clean/*/marker_labels.avi` | 81 MB | Pre-rendered label overlays. Superseded by `frames.mp4` + `marker_labels.npz`, which the viewer composites on the fly for a fraction of the size. |
| `silicone_training_data/20250901-131547{,_interpolated_trimmed,_markers,_dilated,...}` | ~1.05 GB | Intermediate silicone preprocessing stages; only the final `_dense` directory is consumed. |
| `system-id-screws-*.mkv`, `vein_slide_across.avi`, `domain-adaptation-vascular-videos/` | ~960 MB | Videos used for system identification and exploratory analysis, not for the published results. |
| `difftactile/output/*` (meshes, voronoi, marker_tracker, debug images) | ~60 MB | All regenerated by `script_pre_main` / `script_generate_*_mesh_gmsh` / `script_marker_tracker`. |
| `difftactile/output/vessel_maps/` (all but the latest run per configuration), `da_recordings/`, `videos_raw/`, `pr_curves/`, `roc_curves/`, `alignment_figures/`, `da_snapshots*/`, `domain_adaptation/<other runs>/` and their `snapshots/` | ~1 GB | Superseded / intermediate runs and renders. Every run of `vessel_map.sh`, `record_da_trajectories.sh` and `domain_adaptation.sh` gets a fresh timestamped directory, so these accumulate; only the published run of each is shipped (see `manuscript_artifacts/` and `domain_adaptation_published/`). The demonstration videos are in the git repository (`videos/`), not the bundle. |
| `saved_models_sweeps/<other timestamps>/`, `saved_models_*/*_retrained_*` , `stale_artifacts_pre_new_dataset_20260815/` | ~200 MB | Earlier sweeps (clip_len 7, the pre-regeneration dataset), local `--train` outputs and pre-2026-08-15 artifacts, all superseded by the published sweep `20260815-194045`. |
| `difftactile/output/exp_probs.npz` | 424 KB | Cached per-marker probabilities for the bird's-eye vessel map. Pure model output: `./docker/vessel_map.sh` recomputes it from the shipped silicone dataset + meat checkpoint in **under a second**, bit-identically. Only `--cached` reuses it, and that flag is an optimisation, not a requirement. |
| `difftactile/output/phantom_ground_truth_segmentation_mask.jpg` and the other `*ground_truth*` images | ~150 KB | Regenerated bit-identically by `script_annotate` from two **git-tracked** inputs (`phantom-labels-vgg.json`, `phantom-uncropped-compressed-undistorted.jpg`), so they are in the repository already, not missing. The remaining `ground_truth_*` images are written by `predict_exp` itself during the same run. |
| `lightning_logs/`, `logs/` | 68 MB | Training logs from the original runs; recreated on any new training run. |

Excluding these takes the bundle from **4.5 GB to roughly 375 MB (~275 MB compressed)** without
affecting the reproducibility of any published result.

## Restoring

From the repository root:

```bash
./data/restore_data.sh path/to/shallow-vessel-palpation-data.tar.gz
```

The script unpacks into the correct locations and verifies each expected path
afterwards. See `data/restore_data.sh --help` for options.

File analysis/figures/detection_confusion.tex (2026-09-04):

% GENERATED by scripts/detection_bars.py -- do not edit by hand.
% Sim->Meat, centrelines, video-frame space: how many vessels the model finds in a frame
% against how many the ground truth holds. Rows are the truth, columns the prediction,
% cells are numbers of frames shaded by their share of the row.
		\begin{tabular}{@{}l r r r r@{}}
			\toprule
			& \multicolumn{4}{c}{\textbf{predicted}}\\
			\cmidrule(l){2-5}
			\textbf{true} & 0 & 1 & 2 & 3$+$\\
			\midrule
			0 & \cellcolor{ICLBlue!22}\textbf{43} & \cellcolor{ICLBlue!10}20 & \cellcolor{ICLBlue!4}7 & \cellcolor{ICLBlue!10}20 \\
			1 & \cellcolor{ICLBlue!7}16 & \cellcolor{ICLBlue!14}\textbf{31} & \cellcolor{ICLBlue!16}37 & \cellcolor{ICLBlue!8}19 \\
			2 & 0 & \cellcolor{ICLBlue!24}9 & \cellcolor{ICLBlue!13}\textbf{5} & \cellcolor{ICLBlue!8}3 \\
			3 & 0 & \cellcolor{ICLBlue!35}7 & \cellcolor{ICLBlue!10}2 & \textbf{0} \\
			\bottomrule
		\end{tabular}

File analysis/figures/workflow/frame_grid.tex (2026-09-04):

% GENERATED by scripts/workflow_centreline_panels.py -- do not edit by hand.
% 4x4 grid of frame-space panels: rows are the ground-truth vessel count 0..3,
% columns are the four models, and the key spans the grid on the right. Axes are
% drawn once per edge (left column, bottom row) and their margins hang outside the
% grid, so the plot boxes stay flush. The block's top-left corner is (0, 0) and it
% grows right and down; (fgtl) and (fgbr) mark its corners for a fit= group node.
\coordinate (fgtl) at (0, 0);
\coordinate (fgbr) at (25.706, -20.078);
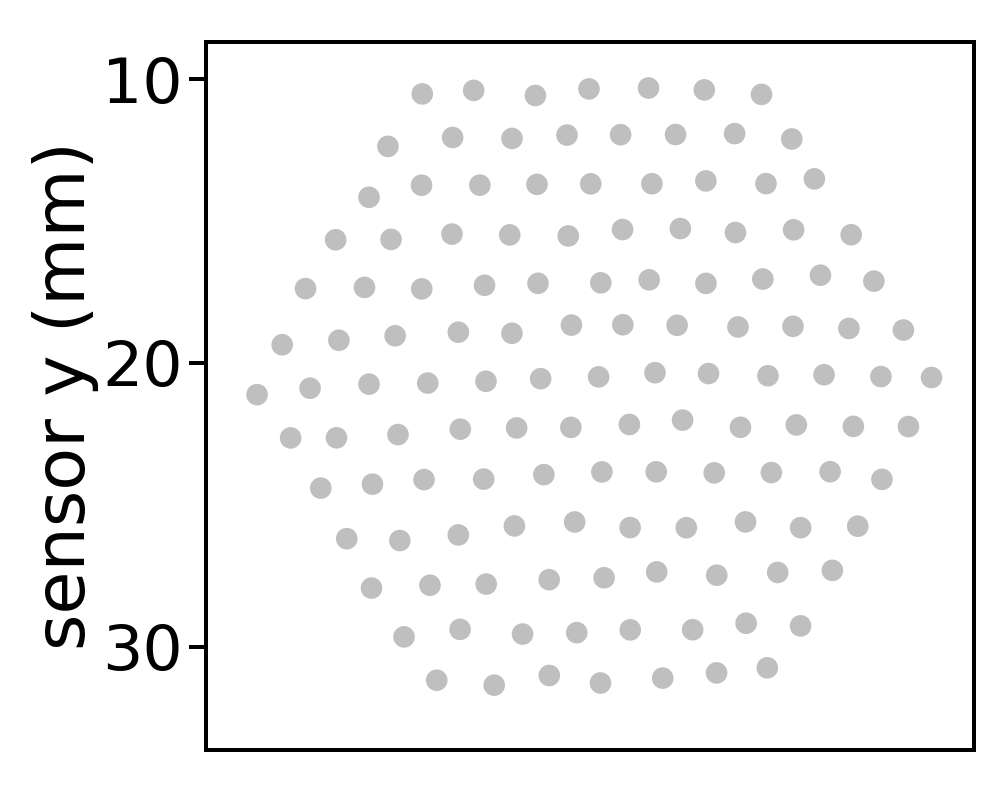
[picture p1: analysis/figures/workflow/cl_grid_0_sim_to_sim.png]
\node[bimg] (fg00) at (0.800, -0.850) {};
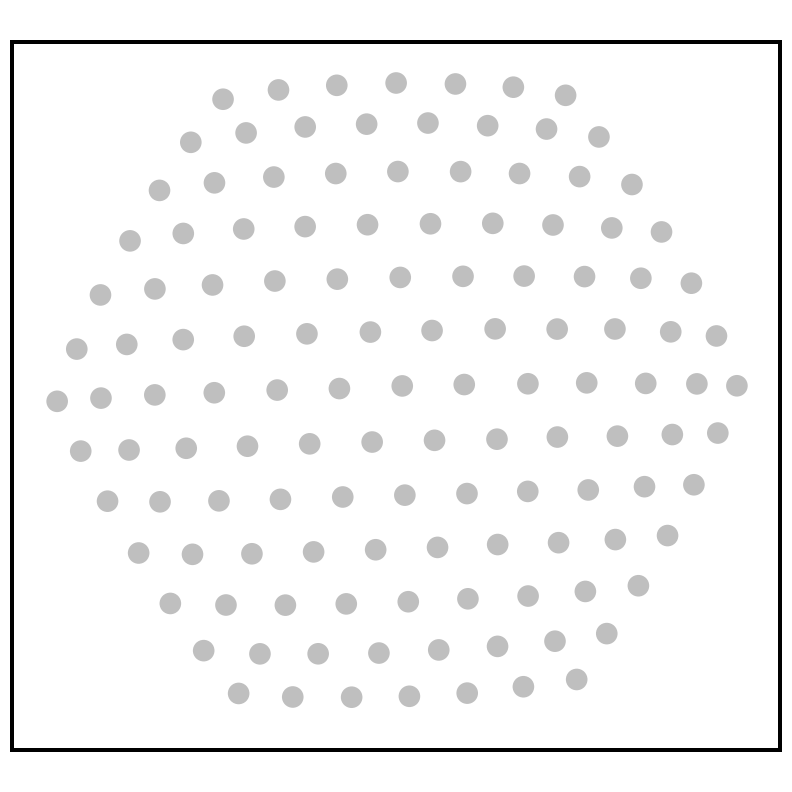
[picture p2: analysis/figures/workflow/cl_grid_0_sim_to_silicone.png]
\node[bimg] (fg01) at (6.474, -0.850) {};
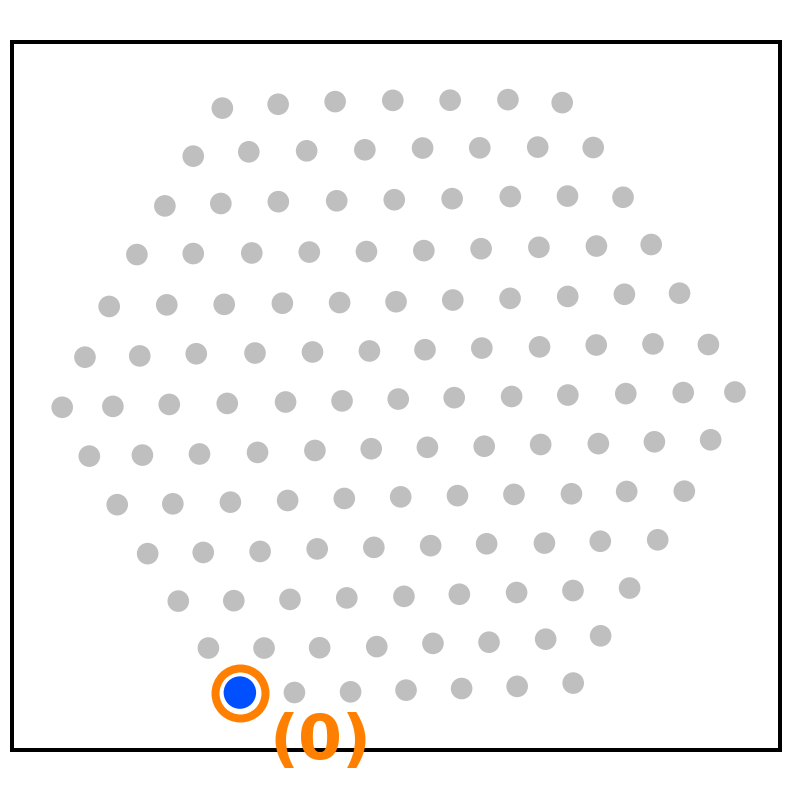
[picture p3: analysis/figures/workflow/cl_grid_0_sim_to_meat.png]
\node[bimg] (fg02) at (11.086, -0.850) {};
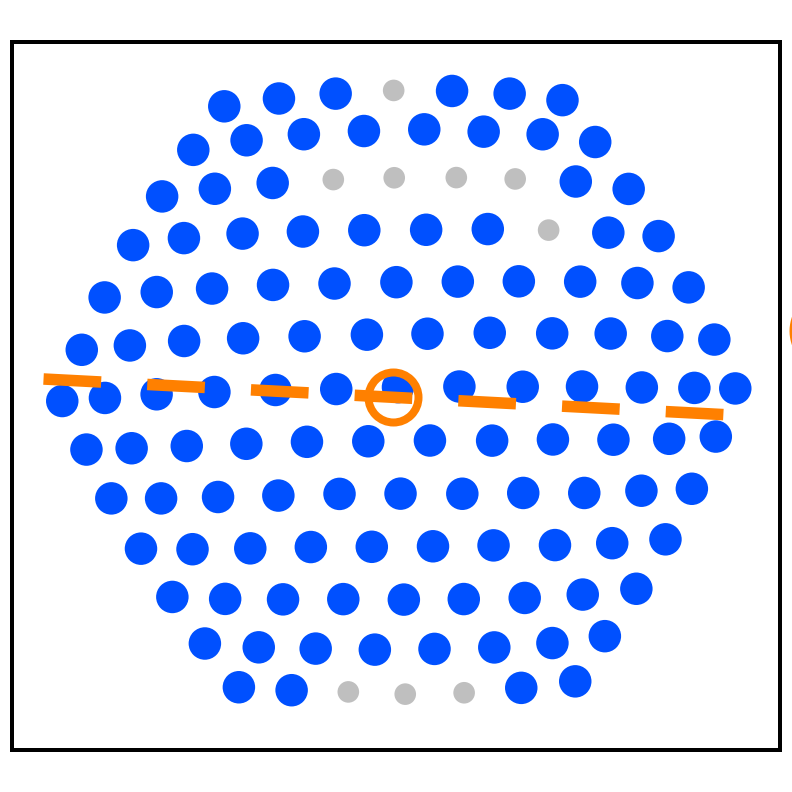
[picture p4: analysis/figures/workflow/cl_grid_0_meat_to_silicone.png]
\node[bimg] (fg03) at (15.697, -0.850) {};
\node[bsub, rotate=90, anchor=south] at (0.700, -3.016) {0 vessels};
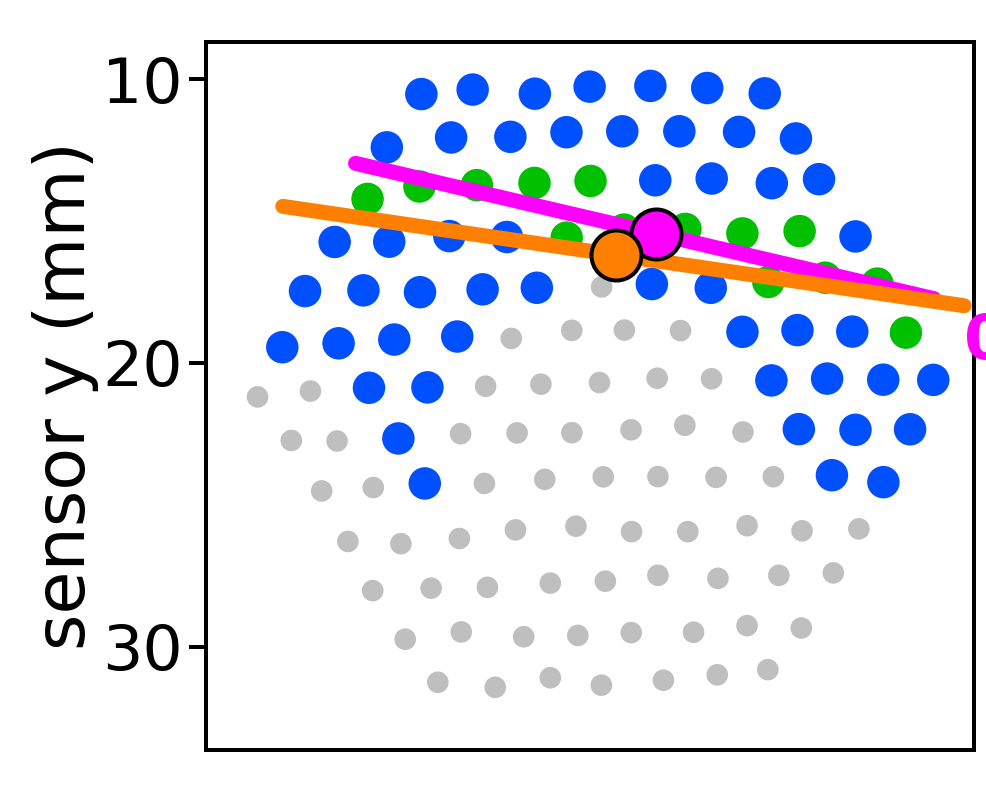
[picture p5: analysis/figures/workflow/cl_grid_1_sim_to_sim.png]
\node[bimg] (fg10) at (0.800, -5.461) {};
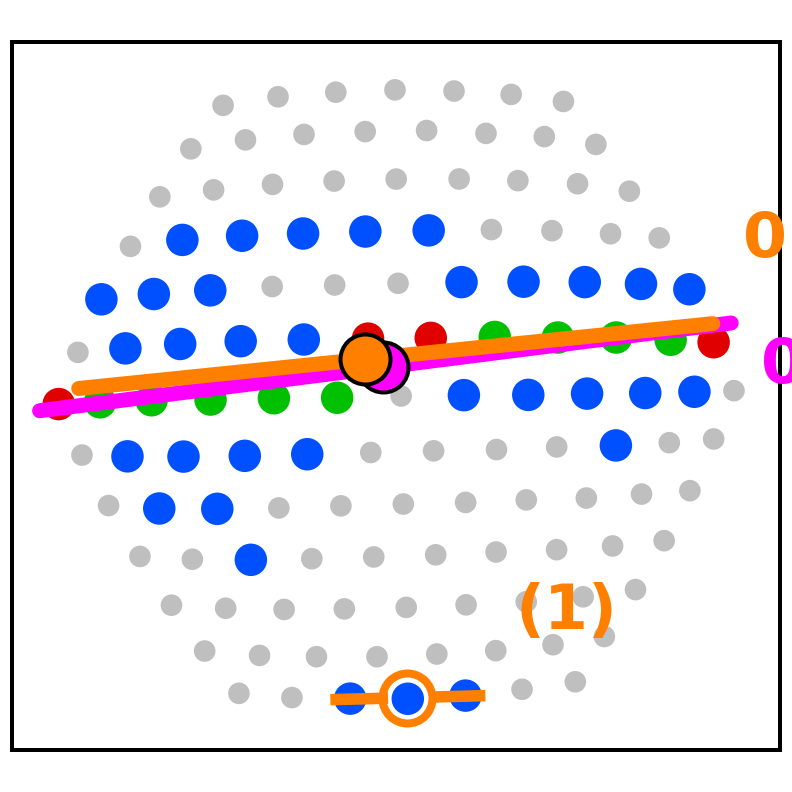
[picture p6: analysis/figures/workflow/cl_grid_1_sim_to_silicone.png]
\node[bimg] (fg11) at (6.474, -5.461) {};
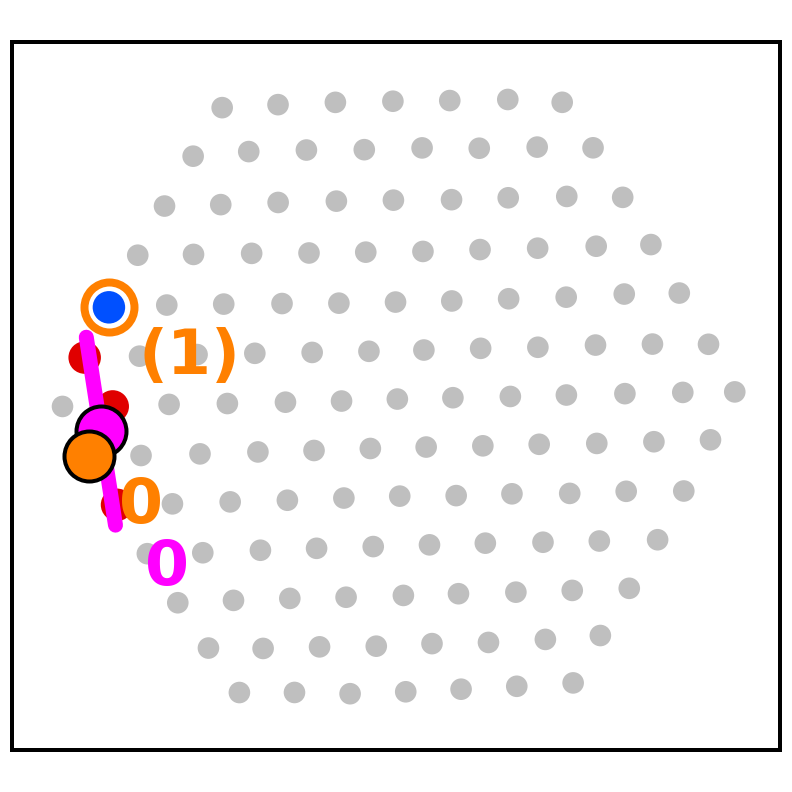
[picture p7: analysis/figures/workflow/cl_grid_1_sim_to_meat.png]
\node[bimg] (fg12) at (11.086, -5.461) {};
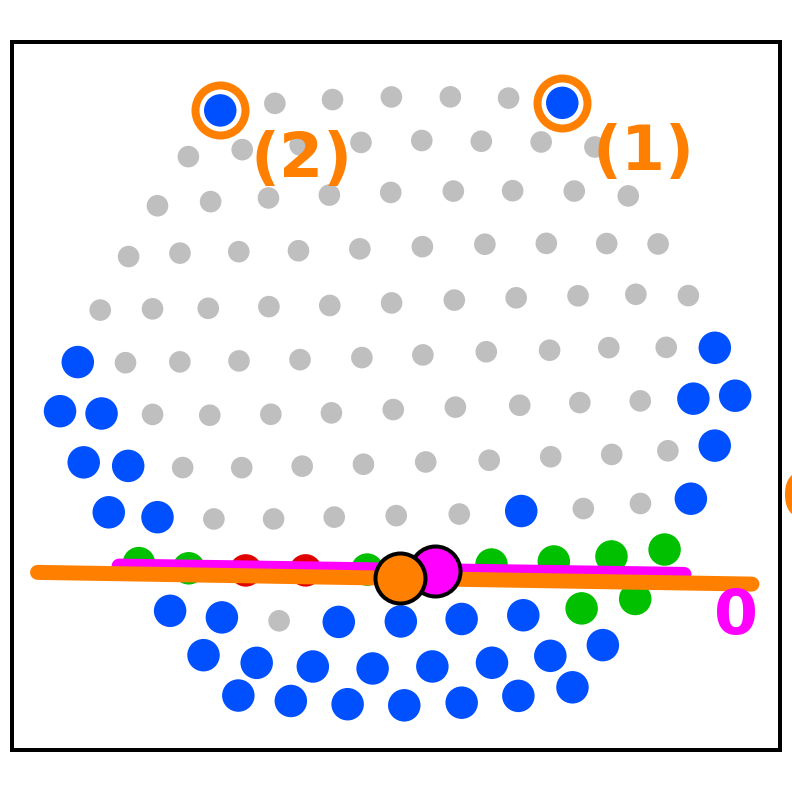
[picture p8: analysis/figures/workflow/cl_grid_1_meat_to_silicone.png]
\node[bimg] (fg13) at (15.697, -5.461) {};
\node[bsub, rotate=90, anchor=south] at (0.700, -7.627) {1 vessel};
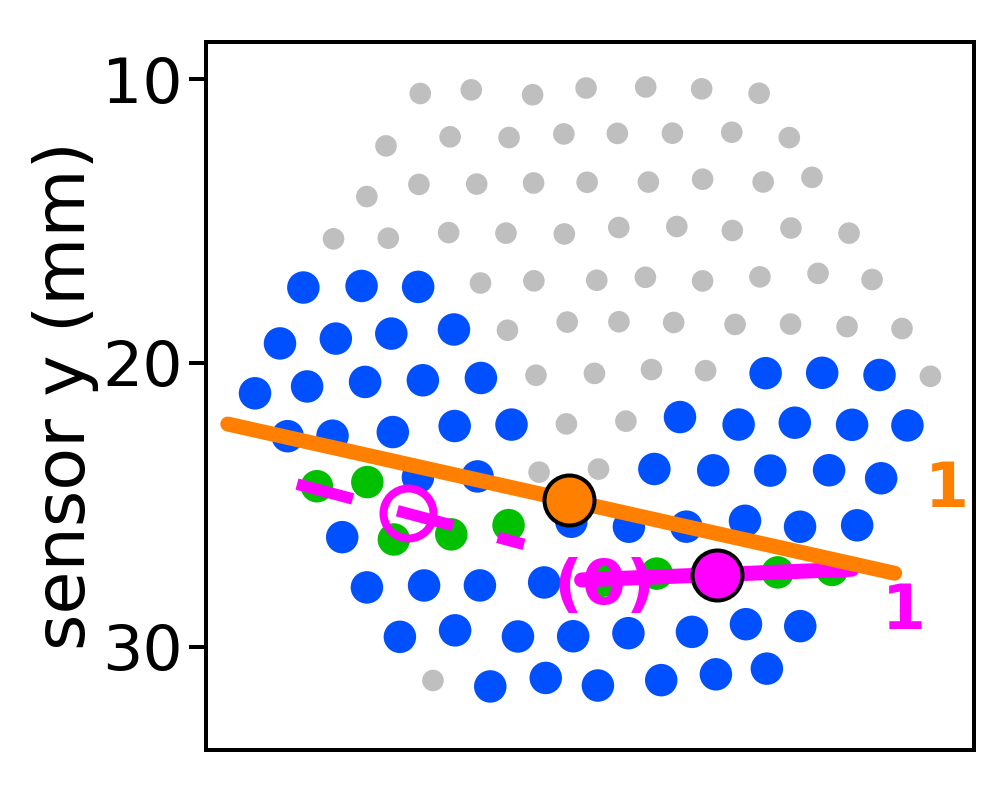
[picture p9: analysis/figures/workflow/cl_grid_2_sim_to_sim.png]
\node[bimg] (fg20) at (0.800, -10.072) {};
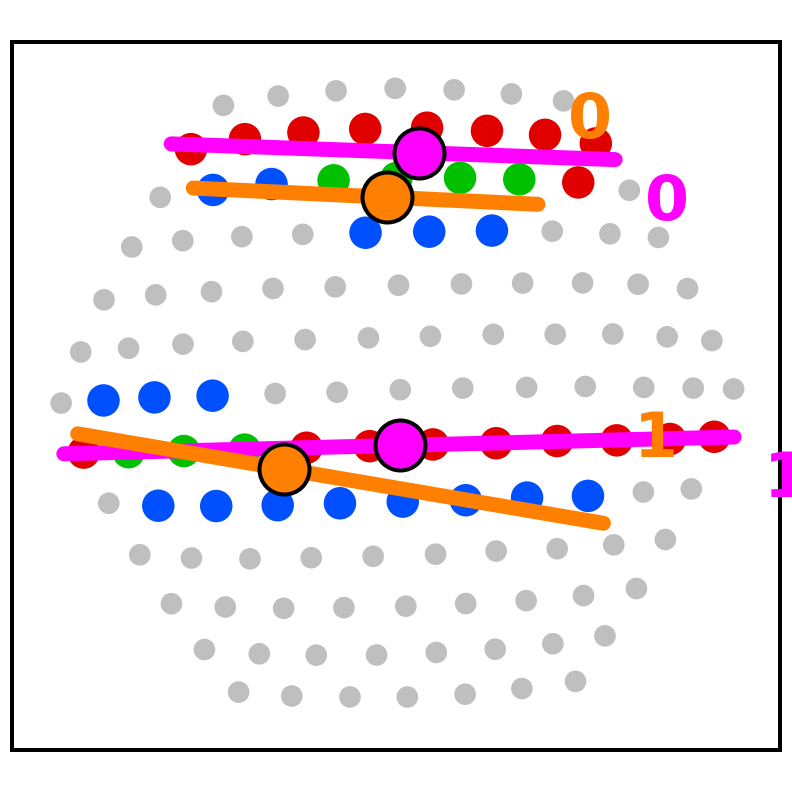
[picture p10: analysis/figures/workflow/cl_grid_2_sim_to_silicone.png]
\node[bimg] (fg21) at (6.474, -10.072) {};
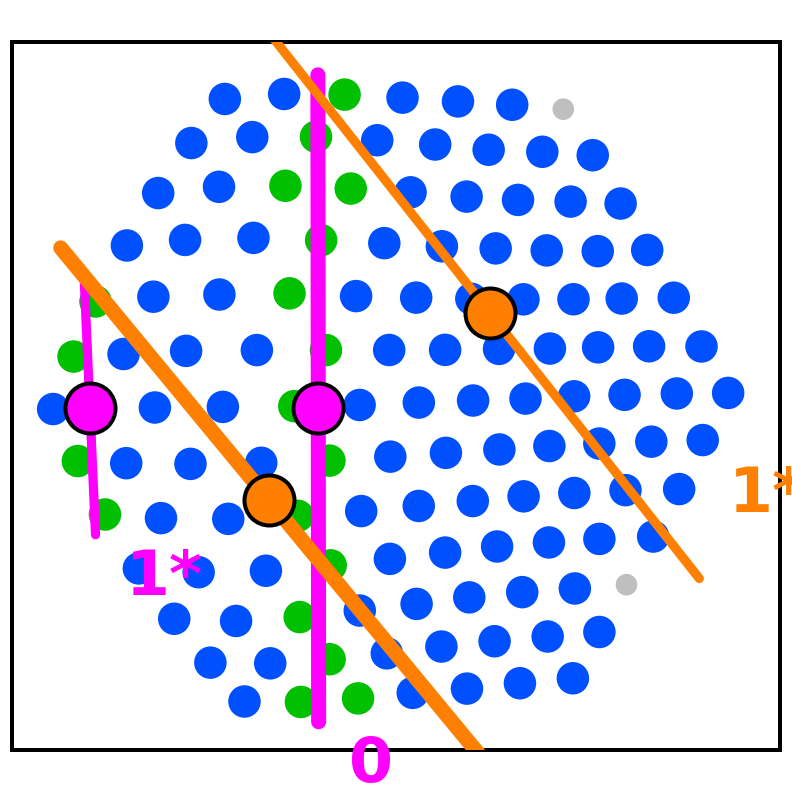
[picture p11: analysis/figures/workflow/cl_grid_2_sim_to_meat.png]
\node[bimg] (fg22) at (11.086, -10.072) {};
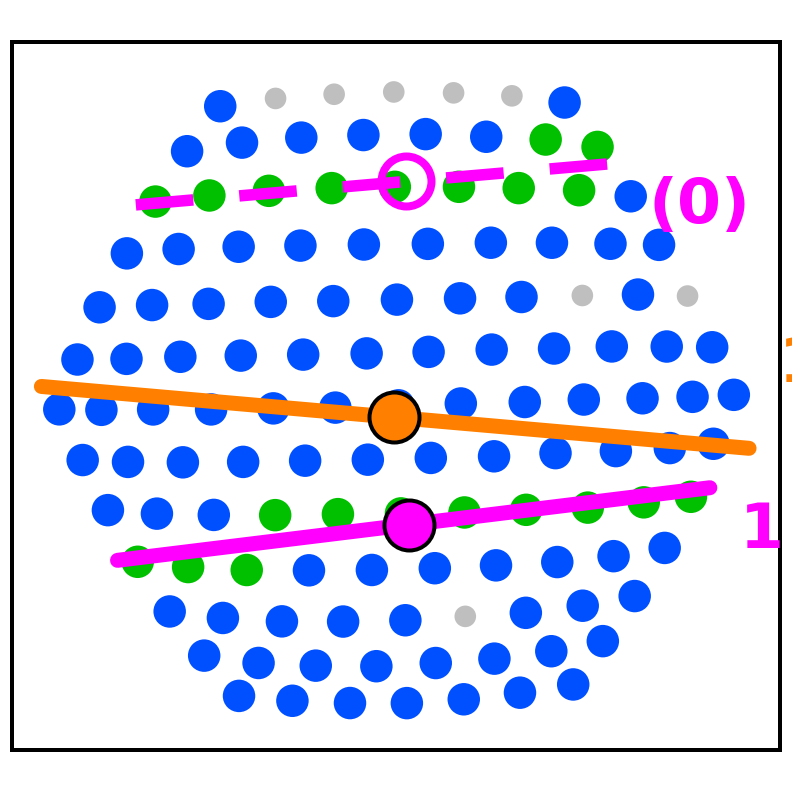
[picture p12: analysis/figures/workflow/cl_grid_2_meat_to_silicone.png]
\node[bimg] (fg23) at (15.697, -10.072) {};
\node[bsub, rotate=90, anchor=south] at (0.700, -12.238) {2 vessels};
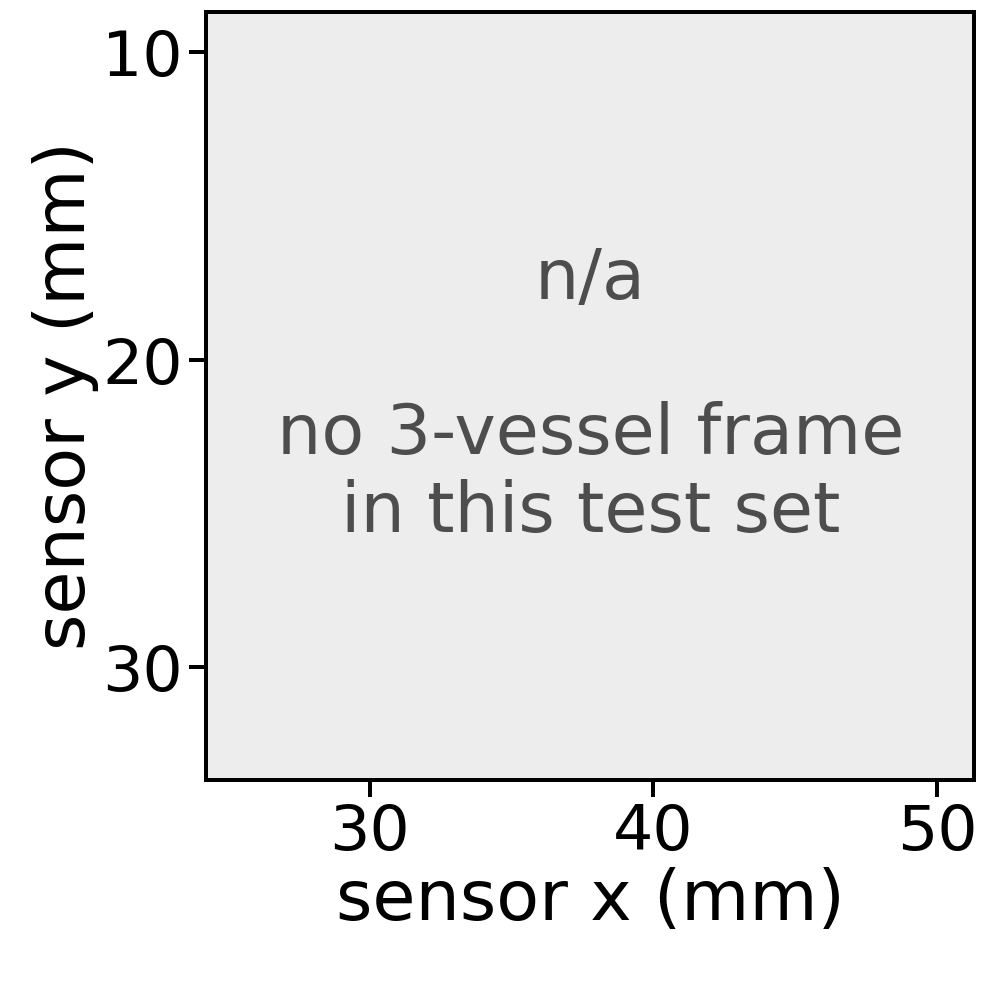
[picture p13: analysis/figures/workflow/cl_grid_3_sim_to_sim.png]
\node[bimg] (fg30) at (0.800, -14.684) {};
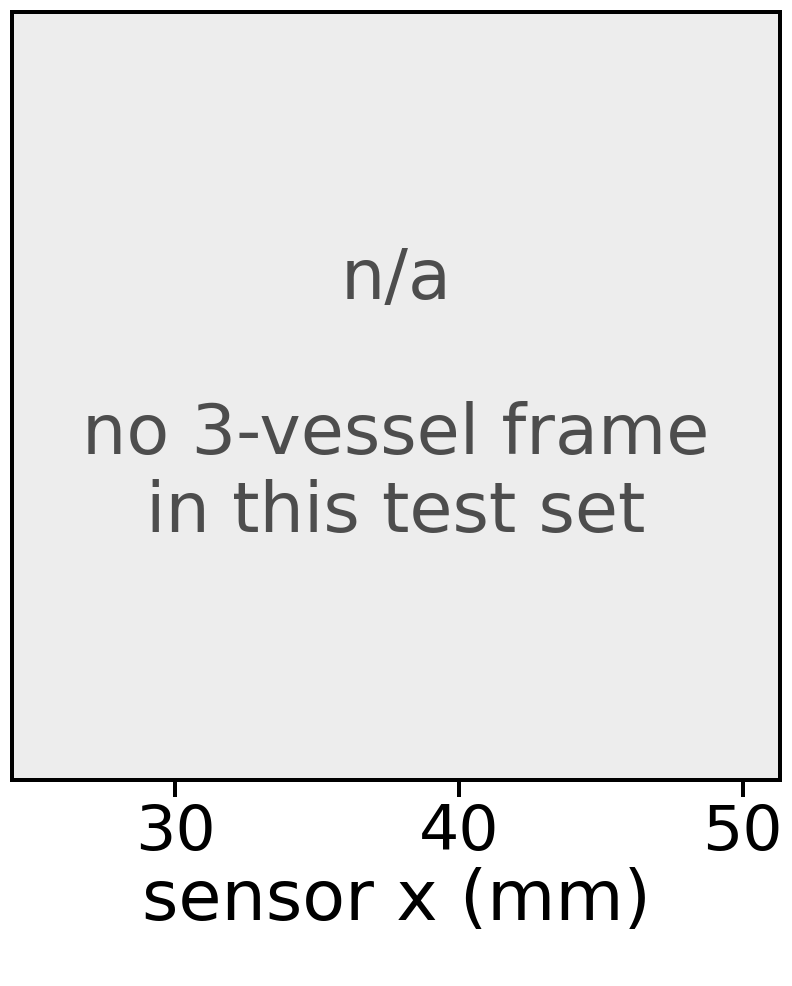
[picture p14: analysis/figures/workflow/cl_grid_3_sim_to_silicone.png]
\node[bimg] (fg31) at (6.474, -14.684) {};
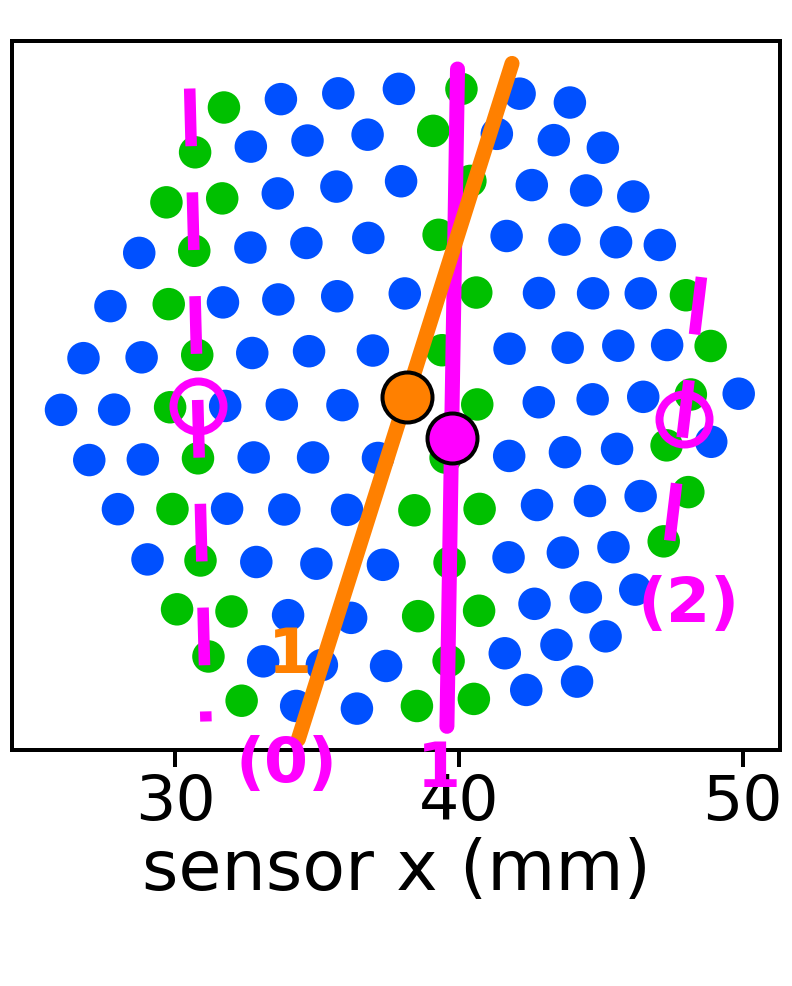
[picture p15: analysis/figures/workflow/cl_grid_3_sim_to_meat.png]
\node[bimg] (fg32) at (11.086, -14.684) {};
\node[bimg] (fg33) at (15.697, -14.684) {};
\node[bsub, rotate=90, anchor=south] at (0.700, -16.849) {3 vessels};
\node[bsub, anchor=south] at (4.029, -0.730) {\msq{MdlA}~Sim$\rightarrow$Sim};
\node[bsub, anchor=south] at (8.640, -0.730) {\msq{MdlB}~Sim$\rightarrow$Silicone};
\node[bsub, anchor=south] at (13.251, -0.730) {\msq{MdlC}~Sim$\rightarrow$Meat};
\node[bsub, anchor=south] at (17.862, -0.730) {\msq{MdlD}~Meat$\rightarrow$Silicone};
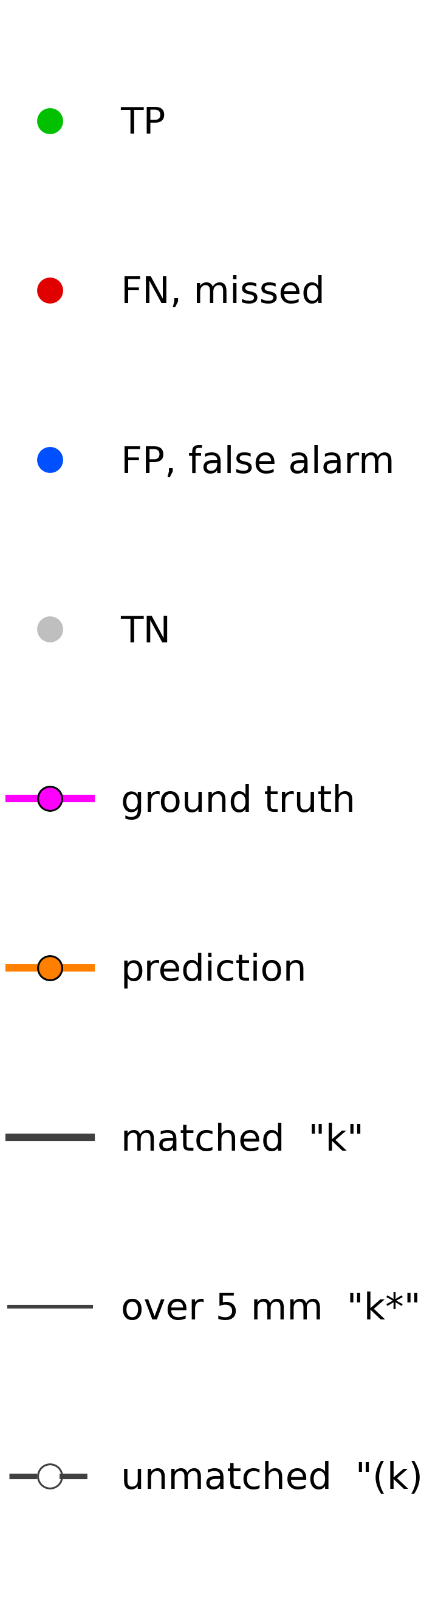
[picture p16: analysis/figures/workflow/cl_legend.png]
\node[bimg] (fgkey) at (20.658, -0.850) {};

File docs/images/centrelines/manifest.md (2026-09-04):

# Vessel centreline / centroid panels on the project page

Written by `docker/website_centreline_panels.sh`, which runs
`analysis/scripts/workflow_centreline_panels.py --all-axes` and converts each panel to
lossless WebP. `--all-axes` is the only difference from the panels the poster prints: the
poster draws the axes on the left column and the bottom row only, so its sixteen cells butt
up flush inside one figure, whereas a web grid scales every cell to one width and would then
render the plots at visibly different sizes.

Every object drawn here comes from exactly the extraction that
`analysis/scripts/detection_ospa.py` scores — same peak finding, same near-duplicate
filtering, same Hungarian matching — so the pictures and the numbers cannot disagree.

**Drawing conventions.** Markers and map pixels carry the project's confusion colours: green =
both say vessel, red = missed vessel (truth only), blue = false alarm (prediction only), grey
or black = neither. **Magenta** is ground truth and **orange** is the prediction; each object
is a straight centreline (total-least-squares fit) with its centroid marked. An index printed
in both colours means the two were matched by the Hungarian assignment; `k*` means matched but
further apart than the 5 mm tolerance; `(k)` in parentheses means unmatched — an invented
vessel in orange, a missed one in magenta.

## Frame-space panels (16)

`cl_grid_<n>_<model>.webp`, one per (ground-truth vessel count `n` = 0…3) × model. Video-frame
space: the sensor's 127 tracked markers, in millimetres on the sensor surface, at the
frame-space operating point (threshold 0.5). All sixteen share one set of axis limits.

Each cell is the frame of that model's test set that is **most representative** of that
difficulty, not the best one: the frame whose OSPA and F₁ both sit closest to the median over
that model's frames *with the same ground-truth vessel count*, in units of the robust spread of
each metric. Stratifying by count matters — 379 of Sim→Sim's 675 frames hold no vessel at all,
and an unstratified median would be theirs.

| n | model | file | frames in stratum | chosen frame | OSPA (mm) | F₁ |
|---|---|---|---:|---|---:|---:|
| 0 | Sim→Sim | `cl_grid_0_sim_to_sim.webp` | 379 | `frame_0000` | 0.00 | 1.00 |
| 0 | Sim→Silicone | `cl_grid_0_sim_to_silicone.webp` | 26 | `frame_0096` | 0.00 | 1.00 |
| 0 | Sim→Meat | `cl_grid_0_sim_to_meat.webp` | 90 | `frame_0064` | 10.00 | 0.00 |
| 0 | Meat→Silicone | `cl_grid_0_meat_to_silicone.webp` | 26 | `frame_0005` | 10.00 | 0.00 |
| 1 | Sim→Sim | `cl_grid_1_sim_to_sim.webp` | 270 | `frame_0395` | 1.05 | 1.00 |
| 1 | Sim→Silicone | `cl_grid_1_sim_to_silicone.webp` | 43 | `frame_0052` | 5.19 | 0.67 |
| 1 | Sim→Meat | `cl_grid_1_sim_to_meat.webp` | 103 | `frame_0048` | 5.55 | 0.67 |
| 1 | Meat→Silicone | `cl_grid_1_meat_to_silicone.webp` | 43 | `frame_0017` | 6.82 | 0.50 |
| 2 | Sim→Sim | `cl_grid_2_sim_to_sim.webp` | 26 | `frame_0335` | 4.09 | 0.67 |
| 2 | Sim→Silicone | `cl_grid_2_sim_to_silicone.webp` | 51 | `frame_0034` | 1.59 | 1.00 |
| 2 | Sim→Meat | `cl_grid_2_sim_to_meat.webp` | 17 | `frame_0180` | 4.59 | 0.50 |
| 2 | Meat→Silicone | `cl_grid_2_meat_to_silicone.webp` | 51 | `frame_0070` | 4.39 | 0.67 |
| 3 | Sim→Sim | `cl_grid_3_sim_to_sim.webp` | 0 | — (placeholder) | — | — |
| 3 | Sim→Silicone | `cl_grid_3_sim_to_silicone.webp` | 0 | — (placeholder) | — | — |
| 3 | Sim→Meat | `cl_grid_3_sim_to_meat.webp` | 9 | `frame_0186` | 4.02 | 0.50 |
| 3 | Meat→Silicone | `cl_grid_3_meat_to_silicone.webp` | 0 | — (placeholder) | — | — |

Three of the sixteen are an explicit "no 3-vessel frame in this test set" placeholder rather
than a blank: only the Meat phantom was built with three straws under one slide.

## Top-view panels (4)

`cl_map_<model>.webp`, one per model, at each map's own aspect ratio. Top-view space: 1 px =
1 mm on the phantom, at each model's own chosen operating point (the vessel-map rule: pixel
precision ≥ 0.9 within 3 mm, recall maximised). Objects are connected components — no peak
finding, because the map builder saves thresholded masks and discards the probability field.

| model | file | map shown | GT vessels | predicted | matched | OSPA (mm) |
|---|---|---|---:|---:|---:|---:|
| Sim→Sim | `cl_map_sim_to_sim.webp` | the single dedicated simulated slide | 1 | 1 | 1 | 0.36 |
| Sim→Silicone | `cl_map_sim_to_silicone.webp` | the whole silicone phantom, all ten sweeps | 10 | 13 | 10 | 4.76 |
| Sim→Meat | `cl_map_sim_to_meat.webp` | `trial_03_1-metal-straw-beneath-3-steaks-20260228-233031`, the median-OSPA trial of ten | 1 | 1 | 1 | 5.00 |
| Meat→Silicone | `cl_map_meat_to_silicone.webp` | the whole silicone phantom, all ten sweeps | 10 | 14 | 10 | 5.06 |

Sim→Meat has ten trial maps rather than one stitched map, so the same representativeness rule
picks among them: the trial whose OSPA is closest to the median over that model's ten.

The recovered ground-truth counts are the physical ones — 1 vessel on the Sim map, 10 on each
silicone whole-phantom map (the ten sweeps the run's `run.json` records) and 1/1/1/1/1/1/1/2/3/0
across the ten meat trials, matching every trial's name including the `no-straw` control.

## Regenerating

```bash
./docker/reproduce_analysis.sh --only 1,4     # per-marker predictions, then the OSPA scoring
./docker/website_centreline_panels.sh         # these images
```

Source numbers: `analysis/results/workflow_panel_choice.json` (which frame each cell shows and
why) and `analysis/results/detection_ospa.json` (the pooled metrics).

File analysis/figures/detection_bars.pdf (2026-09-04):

Sim→
Sim

Sim→
Silicone

Sim→
Meat

Meat→
Silicone
0.85 | 0.77
0.42 | 0.37

Detection F1 at 5 mm ↑

Sim→
Sim

Sim→
Silicone

Sim→
Meat

Meat→
Silicone

0.91

3.20

5.07

5.97

Localisation error, OSPA [mm] ↓

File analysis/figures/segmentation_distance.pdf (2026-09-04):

Sim→
Sim

Sim→
Silicone

Sim→
Meat

Meat→
Silicone

3.03
2.16
4.12 | 3.87

Video frame, per marker [mm] ↓

Sim→
Sim

Sim→
Silicone

Sim→
Meat

Meat→
Silicone
1.05 | 1.21

5.49

1.31

Top-view map, per pixel [mm] ↓

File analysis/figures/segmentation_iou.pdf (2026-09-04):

Sim→
Sim

Sim→
Silicone

Sim→
Meat

Meat→
Silicone
0.19 | 0.24
0.17 | 0.16

Video frame, per marker ↑

Sim→
Sim

Sim→
Silicone

Sim→
Meat

Meat→
Silicone

0.42
0.28
0.21

0.31

Top-view map, per pixel ↑

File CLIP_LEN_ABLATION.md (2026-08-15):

# Clip-length ablation

How many video frames should the GNN see at once? The model takes a
`clip_len`-frame window of marker positions and predicts the central frame;
this trains the A-to-B configuration (train on simulation, test on real
silicone) at each window length and scores it on the silicone test set.

Each row is 3 training run(s) (seeds 0, 1, 2),
reported as mean ± std - single runs on this project reflect their seed as much
as the model (see the seed sweep in AUROC_RESULTS.md).

**The deciding metric is foreground IoU** (the vessel-present class, at the
standard decision threshold); AUROC and AP are context.

| clip_len | Foreground IoU mean ± std | Foreground IoU range | AUROC mean ± std | AP mean ± std |
|---|---|---|---|---|
| 1 | **0.1142 ± 0.0018** | 0.1123–0.1157 | 0.5815 ± 0.0030 | 0.2094 ± 0.0054 |
| 3 | **0.1967 ± 0.0059** | 0.1900–0.2011 | 0.7403 ± 0.0024 | 0.2008 ± 0.0012 |
| 5 **(best)** | **0.2384 ± 0.0012** | 0.2371–0.2394 | 0.7818 ± 0.0018 | 0.3243 ± 0.0011 |
| 7 | **0.2139 ± 0.0294** | 0.1799–0.2310 | 0.7676 ± 0.0078 | 0.3105 ± 0.0061 |

Checkpoints and per-run artifacts: `saved_models_ablation/20260815-193236/clip_len_XX/`;
`ablation.json` there repeats these numbers in machine-readable form.

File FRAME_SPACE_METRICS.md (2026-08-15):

# Video-frame-space metrics (best-of-five instance per model, pooled once)

Per-marker predictions of every central frame of every clip of every trial, pooled
into one set and scored once at threshold 0.5; AP is threshold-free.
No averaging over trials, clips or seeds. The instance is the best-of-five by AP
(cnn/model_selection.py) - the same one the top-view maps use.

| Model | n | positives | TP | FP | FN | TN | MCC | F1 | Prec. | Rec. | FG IoU | BG IoU | AP | chance |
|---|---|---|---|---|---|---|---|---|---|---|---|---|---|---|
| Sim→Sim (A-to-A) | 85725 | 3607 | 3569 | 15169 | 38 | 66949 | 0.39 | 0.32 | 0.19 | 0.99 | 0.19 | 0.81 | 0.50 | 0.042 |
| Sim→Silicone (A-to-B) | 15240 | 1727 | 909 | 2070 | 818 | 11443 | 0.30 | 0.39 | 0.31 | 0.53 | 0.24 | 0.80 | 0.33 | 0.113 |
| Sim→Meat (A-to-C) | 27813 | 1810 | 1493 | 7134 | 317 | 18869 | 0.29 | 0.29 | 0.17 | 0.82 | 0.17 | 0.72 | 0.23 | 0.065 |
| Meat→Silicone (C-to-B) | 15240 | 1727 | 1600 | 8448 | 127 | 5065 | 0.20 | 0.27 | 0.16 | 0.93 | 0.16 | 0.37 | 0.35 | 0.113 |

Instances:
- A-to-A best-of-5 seeds (seed 1, AP 0.4977, AUROC 0.9589) from sweep 20260815-194045
- A-to-B best-of-5 seeds (seed 2, AP 0.3255, AUROC 0.7832) from sweep 20260815-194045
- A-to-C best-of-5 seeds (seed 2, AP 0.2279, AUROC 0.8405) from sweep 20260815-194045
- C-to-B best-of-5 seeds (seed 4, AP 0.3481, AUROC 0.7874) from sweep 20260815-194045

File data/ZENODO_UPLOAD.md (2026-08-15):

# Uploading the data bundle to Zenodo from the command line

**Short answer: yes.** A `.tar.gz` can be uploaded entirely from an Ubuntu
terminal — the web form is not required. Zenodo's REST API accepts a plain
`curl` PUT, which is also *more reliable* than the browser for large files,
because it can be retried and resumed rather than restarting from zero.

Everything below needs only `curl` and `jq` (`sudo apt install curl jq`).

## 1. Create an access token (one-time, in the browser)

Zenodo → *Account* → *Applications* → *Personal access tokens* → *New token*.
Tick the scopes **`deposit:write`** and **`deposit:actions`**.

Keep it out of your shell history and out of git:

```bash
read -rs ZENODO_TOKEN && export ZENODO_TOKEN
```

## 2. Create a draft deposition

```bash
curl -s -H "Authorization: Bearer $ZENODO_TOKEN" \
     -H "Content-Type: application/json" \
     -X POST https://zenodo.org/api/deposit/depositions \
     -d '{}' | tee deposition.json | jq '{id, links}'
```

Capture the two values the next steps need:

```bash
DEPOSITION_ID=$(jq -r .id deposition.json)
BUCKET_URL=$(jq -r .links.bucket deposition.json)
```

## 3. Upload the tarball

The bucket API streams the file, so a multi-GB archive is fine. `--retry`
makes a dropped connection recoverable, which is the main advantage over the
web uploader:

```bash
curl --progress-bar \
     --retry 5 --retry-delay 5 --retry-connrefused \
     -H "Authorization: Bearer $ZENODO_TOKEN" \
     --upload-file shallow-vessel-palpation-data.tar.gz \
     "$BUCKET_URL/shallow-vessel-palpation-data.tar.gz" | jq '{key, size, checksum}'
```

Verify the reported `checksum` (an MD5) against the local file:

```bash
md5sum shallow-vessel-palpation-data.tar.gz
```

## 4. Attach metadata

```bash
curl -s -H "Authorization: Bearer $ZENODO_TOKEN" \
     -H "Content-Type: application/json" \
     -X PUT "https://zenodo.org/api/deposit/depositions/$DEPOSITION_ID" \
     -d @- <<'JSON' | jq '.metadata.title'
{
  "metadata": {
    "title": "Data for: Sim-to-Real Subsurface Feature Localisation with an Optical Tactile Sensor",
    "upload_type": "dataset",
    "description": "Simulated training dataset, preprocessed real silicone- and meat-phantom tactile trials, and trained GNN checkpoints accompanying the shallow-vessel-palpation-simulator-and-AI and shallow-vessel-palpation-robot-control repositories. See MANIFEST.md inside the archive for a full description of contents.",
    "creators": [
      {"name": "Blaszyk, Piotr"}
    ],
    "access_right": "open",
    "license": "cc-by-4.0"
  }
}
JSON
```

## 5. Publish

Publishing mints the DOI and is **irreversible** — files cannot be removed from
a published record afterwards (only superseded by a new version). Check the
draft in the browser first, then:

```bash
curl -s -H "Authorization: Bearer $ZENODO_TOKEN" \
     -X POST "https://zenodo.org/api/deposit/depositions/$DEPOSITION_ID/actions/publish" \
     | jq '{doi, links: .links.record_html}'
```

## Sandbox first (recommended)

Rehearse the whole flow against `https://sandbox.zenodo.org` (separate account
and separate token) by substituting the host in every URL above. Sandbox records
are disposable, so a mistake costs nothing.

## One file or two?

One archive is simpler to cite and to download. Split into two only if you also
want to publish the **raw** experimental recordings (~1.6 GB of `.avi`), which
are excluded from the default bundle — in that case ship
`shallow-vessel-palpation-data.tar.gz` (the ~275 MB reproduction bundle) and
`difftactile-raw-recordings.tar.gz` separately, so users who only want to verify
results are not forced to download the raw videos.

## Alternative: a wrapper tool

If you would rather not hand-roll `curl`, `zenodo-uploader` and `zenodo_client`
(both `pip install`-able) wrap the same API. They add nothing the commands above
lack, so the plain-`curl` route is preferred here — no extra dependency, and
every step is visible.

Sources:
- [Zenodo REST API — developers.zenodo.org](https://developers.zenodo.org/)
- [jhpoelen/zenodo-upload (curl + bash reference implementation)](https://github.com/jhpoelen/zenodo-upload)
- [zenodo-uploader on PyPI](https://pypi.org/project/zenodo-uploader/)
- [zenodo_client on PyPI](https://pypi.org/project/zenodo-client/)

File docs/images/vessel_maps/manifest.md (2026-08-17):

# Bird's-eye vessel maps on the project page

Written by `docker/website_vessel_maps.sh` (`website_vessel_maps.py`). Each image is a run's `confusion_r00.png` (1 px = 1 mm, ground truth not grown) upscaled x5 nearest-neighbour and saved as lossless WebP. Colours: green = both say vessel, red = missed vessel (truth only), blue = false alarm (prediction only), black = neither.

## A-to-A (sim -> sim), ground truth from simulator

Run: `difftactile/output/vessel_maps/sim-to-sim-test-trajectories_gt-simulator/20260817-131622`  
Model: A-to-A best-of-5 seeds (seed 1, AP 0.4977, AUROC 0.9589) from sweep 20260815-194045  
Threshold: precision >= 0.9 (within 3 mm) reached; recall maximised at threshold 0.6222 (precision 0.900, recall 0.622, 2412 predicted pixels)

| # | file | map (run subfolder) | description | size (mm, w x h) |
|---|---|---|---|---|
| 1 | `sim_to_sim_map_01_trajectory_0474_vessel-present.webp` | `map_01_trajectory_0474_vessel-present` | simulated slide trajectory_0474 (vessel-present), map 1 of 10 in the prediction video's order | 66 x 50 |
| 2 | `sim_to_sim_map_02_trajectory_0478_vessel-present.webp` | `map_02_trajectory_0478_vessel-present` | simulated slide trajectory_0478 (vessel-present), map 2 of 10 in the prediction video's order | 66 x 50 |
| 3 | `sim_to_sim_map_03_trajectory_0463_vessel-absent.webp` | `map_03_trajectory_0463_vessel-absent` | simulated slide trajectory_0463 (vessel-absent), map 3 of 10 in the prediction video's order | 66 x 50 |
| 4 | `sim_to_sim_map_04_trajectory_0430_vessel-present.webp` | `map_04_trajectory_0430_vessel-present` | simulated slide trajectory_0430 (vessel-present), map 4 of 10 in the prediction video's order | 66 x 50 |
| 5 | `sim_to_sim_map_05_trajectory_0458_vessel-present.webp` | `map_05_trajectory_0458_vessel-present` | simulated slide trajectory_0458 (vessel-present), map 5 of 10 in the prediction video's order | 66 x 50 |
| 6 | `sim_to_sim_map_06_trajectory_0485_vessel-absent.webp` | `map_06_trajectory_0485_vessel-absent` | simulated slide trajectory_0485 (vessel-absent), map 6 of 10 in the prediction video's order | 66 x 50 |
| 7 | `sim_to_sim_map_07_trajectory_0490_vessel-present.webp` | `map_07_trajectory_0490_vessel-present` | simulated slide trajectory_0490 (vessel-present), map 7 of 10 in the prediction video's order | 66 x 50 |
| 8 | `sim_to_sim_map_08_trajectory_0488_vessel-present.webp` | `map_08_trajectory_0488_vessel-present` | simulated slide trajectory_0488 (vessel-present), map 8 of 10 in the prediction video's order | 66 x 50 |
| 9 | `sim_to_sim_map_09_trajectory_0469_vessel-absent.webp` | `map_09_trajectory_0469_vessel-absent` | simulated slide trajectory_0469 (vessel-absent), map 9 of 10 in the prediction video's order | 66 x 50 |
| 10 | `sim_to_sim_map_10_trajectory_0450_vessel-present.webp` | `map_10_trajectory_0450_vessel-present` | simulated slide trajectory_0450 (vessel-present), map 10 of 10 in the prediction video's order | 66 x 50 |

## A-to-B (sim -> silicone), ground truth from video

Run: `difftactile/output/vessel_maps/sim-to-silicone_gt-video/20260817-131640`  
Model: A-to-B best-of-5 seeds (seed 2, AP 0.3255, AUROC 0.7832) from sweep 20260815-194045  
Threshold: precision >= 0.9 (within 3 mm) reached; recall maximised at threshold 0.5739 (precision 0.900, recall 0.234, 1342 predicted pixels)

| # | file | map (run subfolder) | description | size (mm, w x h) |
|---|---|---|---|---|
| 1 | `sim_to_silicone.webp` | `silicone` | silicone phantom, ten sweeps, 180 x 100 mm workspace | 180 x 100 |

## A-to-C (sim -> meat), ground truth from video

Run: `difftactile/output/vessel_maps/sim-to-meat_gt-video/20260817-131643`  
Model: A-to-C best-of-5 seeds (seed 2, AP 0.2279, AUROC 0.8405) from sweep 20260815-194045  
Threshold: PRECISION TARGET NOT REACHED: no threshold gives precision >= 0.9 (within 3 mm) with at least 20 predicted pixels on this run (max reachable precision 0.873); FALLING BACK to the F1-optimal threshold 0.5530 (precision 0.550, recall 0.359, F1 0.434, 6202 predicted pixels)

| # | file | map (run subfolder) | description | size (mm, w x h) |
|---|---|---|---|---|
| 1 | `sim_to_meat_trial_01_1-metal-straw-beneath-1-steak-20260228-232013.webp` | `trial_01_1-metal-straw-beneath-1-steak-20260228-232013` | 1 metal straw beneath 1 steak | 157 x 48 |
| 2 | `sim_to_meat_trial_02_1-metal-straw-beneath-2-steaks-20260228-232632.webp` | `trial_02_1-metal-straw-beneath-2-steaks-20260228-232632` | 1 metal straw beneath 2 steaks | 157 x 48 |
| 3 | `sim_to_meat_trial_03_1-metal-straw-beneath-3-steaks-20260228-233031.webp` | `trial_03_1-metal-straw-beneath-3-steaks-20260228-233031` | 1 metal straw beneath 3 steaks | 157 x 48 |
| 4 | `sim_to_meat_trial_04_1-metal-straw-beneath-4-steaks-20260228-233454.webp` | `trial_04_1-metal-straw-beneath-4-steaks-20260228-233454` | 1 metal straw beneath 4 steaks | 157 x 48 |
| 5 | `sim_to_meat_trial_05_1-metal-straw-beneath-6-steaks-20260228-234337.webp` | `trial_05_1-metal-straw-beneath-6-steaks-20260228-234337` | 1 metal straw beneath 6 steaks | 157 x 48 |
| 6 | `sim_to_meat_trial_06_1-metal-straw-on-top-20260228-230937.webp` | `trial_06_1-metal-straw-on-top-20260228-230937` | 1 metal straw on top | 157 x 48 |
| 7 | `sim_to_meat_trial_07_1-silicone-straw-beneath-2-steaks-20260301-001457.webp` | `trial_07_1-silicone-straw-beneath-2-steaks-20260301-001457` | 1 silicone straw beneath 2 steaks | 157 x 48 |
| 8 | `sim_to_meat_trial_08_2-metal-straws-beneath-2-steaks-20260228-235749.webp` | `trial_08_2-metal-straws-beneath-2-steaks-20260228-235749` | 2 metal straws beneath 2 steaks | 157 x 48 |
| 9 | `sim_to_meat_trial_09_3-metal-straws-beneath-2-steaks-20260301-000849.webp` | `trial_09_3-metal-straws-beneath-2-steaks-20260301-000849` | 3 metal straws beneath 2 steaks | 157 x 48 |
| 10 | `sim_to_meat_trial_10_no-straw-20260228-234824.webp` | `trial_10_no-straw-20260228-234824` | no straw | 157 x 48 |

## C-to-B (meat -> silicone), ground truth from video

Run: `difftactile/output/vessel_maps/meat-to-silicone_gt-video/20260817-131654`  
Model: C-to-B best-of-5 seeds (seed 4, AP 0.3481, AUROC 0.7874) from sweep 20260815-194045  
Threshold: precision >= 0.9 (within 3 mm) reached; recall maximised at threshold 0.6129 (precision 0.900, recall 0.232, 1326 predicted pixels)

| # | file | map (run subfolder) | description | size (mm, w x h) |
|---|---|---|---|---|
| 1 | `meat_to_silicone.webp` | `silicone` | silicone phantom, ten sweeps, 180 x 100 mm workspace | 180 x 100 |

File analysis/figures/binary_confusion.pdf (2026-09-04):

43 47

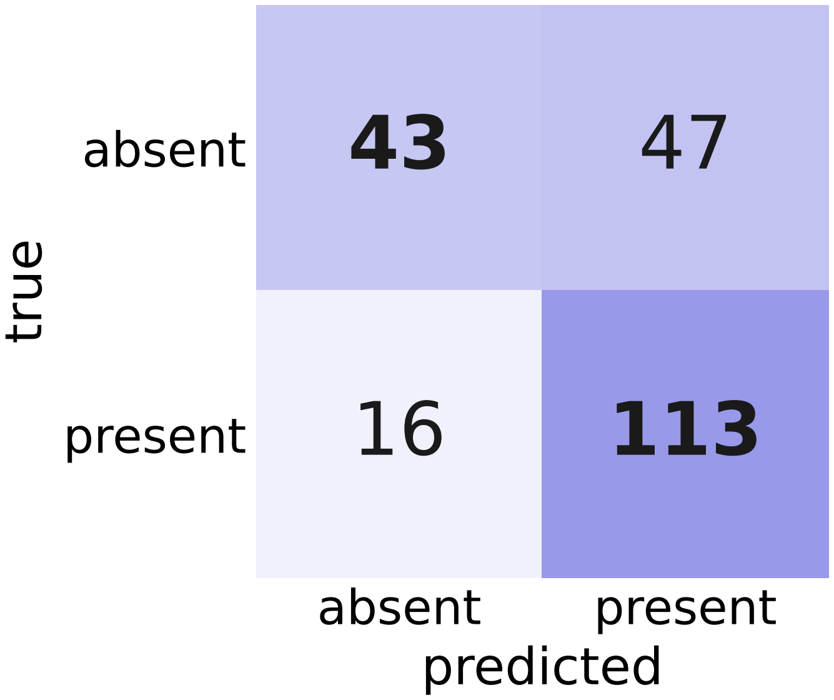
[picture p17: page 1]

absent present
predicted

absent

present

true
16 113

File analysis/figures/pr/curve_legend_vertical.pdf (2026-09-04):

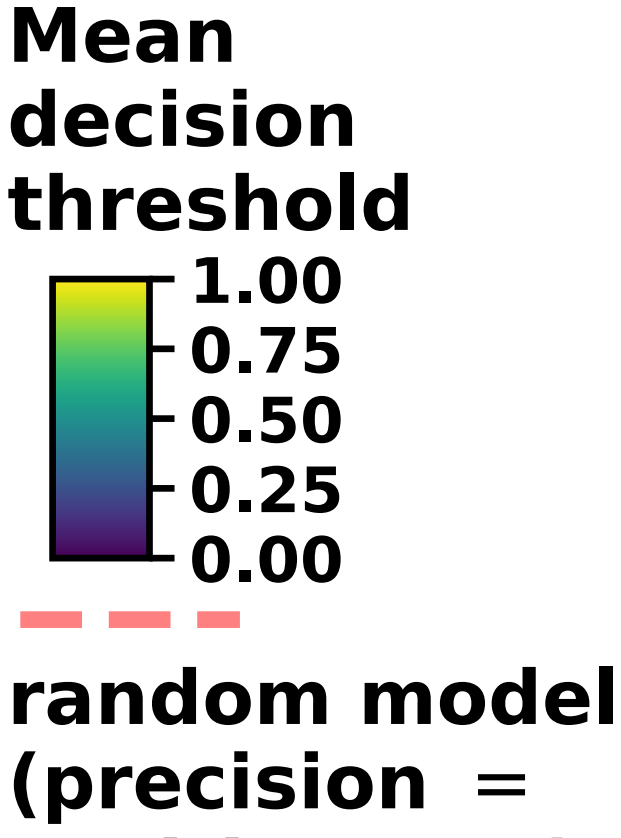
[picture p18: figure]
Mean decision threshold; random model (precision =

positive rate)

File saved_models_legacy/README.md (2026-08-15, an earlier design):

# Legacy models (pre-2026-08-15)

The two checkpoints in this directory - `sim/` (the large simulation-trained
GNN, behind the Sim→Silicone and Sim→Meat models of the accepted manuscript)
and `meat/` (the compact meat-trained GNN, behind Meat→Silicone) - are the
**original** trained weights from the version of this project that was
accepted for publication. Each ships with the `test_loader_gnn_*.pickle`
carrying the normalisation statistics it was trained with; the two files of a
pair must always be used together.

They are kept for one reason: **they produced the accepted manuscript's
bird's-eye vessel map figure (`fig:vessel-map`, Fig. 8) and the localisation
table derived from it (`tab:localisation-map`, Table 4).** Panel (b) of that
figure was completed by hand (the yellow bins were added in a photo editor)
and Table 4 was read off that edited panel; redoing that manual step on new
models was not part of the 2026-08 update, so the figure and table stayed as
they were and the models that made them are preserved here so the artefact
remains traceable.

**They are not used for any of the main results.** Every other number and
figure in the manuscript - the IoU table, the ROC/PR curves, the seed sweep,
the clip-length ablation, the prediction viewer and the regenerated vessel
maps - comes from the current models: five seed instances per configuration
trained on the regenerated simulated dataset with a 5-frame temporal window,
under `saved_models_sweeps/<published sweep>/`, with the best-of-five instance
(by AP) at the published paths `saved_models_sim/` and `saved_models_meat/`.

## Why they cannot be retrained

They were trained on the *previous* simulated dataset
(`pickle_20250901_220921_reordered_dense`), which predates seeding of the
simulator and survives only in pre-2026-08-15 bundle archives, and with a
7-frame temporal window (`gnn.clip_len` was 7; it is 5 now). Their input layer
is sized to that window, so they only load with `DIFFTACTILE_CLIP_LEN=7`,
which the shell entrypoints set for `--model legacy`.

## How to use them

```bash
./docker/vessel_map.sh A-to-B --model legacy    # Sim→Silicone map with the legacy sim model
./docker/vessel_map.sh C-to-B --model legacy    # Meat→Silicone map with the legacy meat model
```

`cnn/model_selection.py::legacy_model()` is the only code path that loads
them, and it refuses any configuration other than A-to-B and C-to-B.

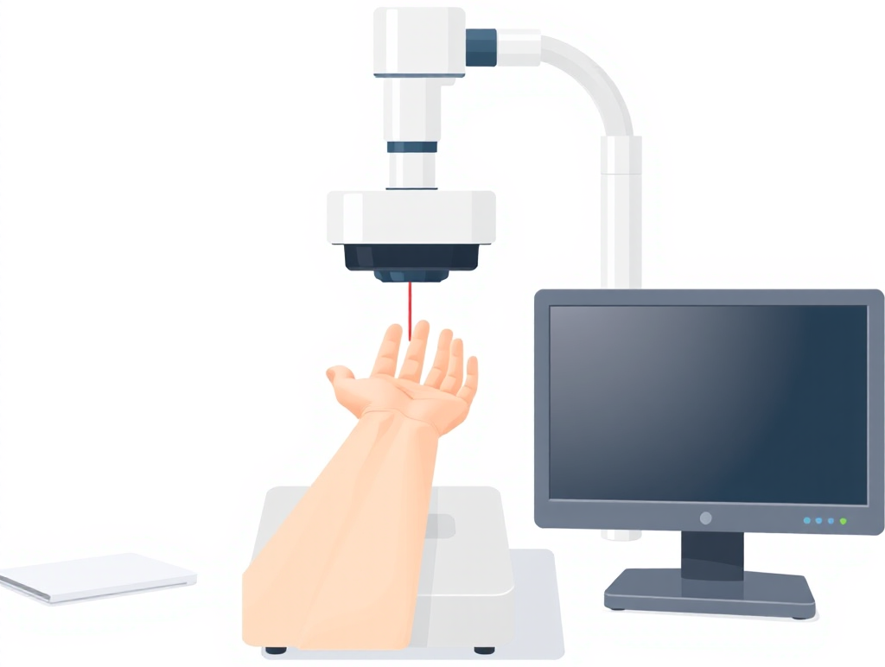
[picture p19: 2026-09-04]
docs/poster-motivation-bibliography/images/oct.png

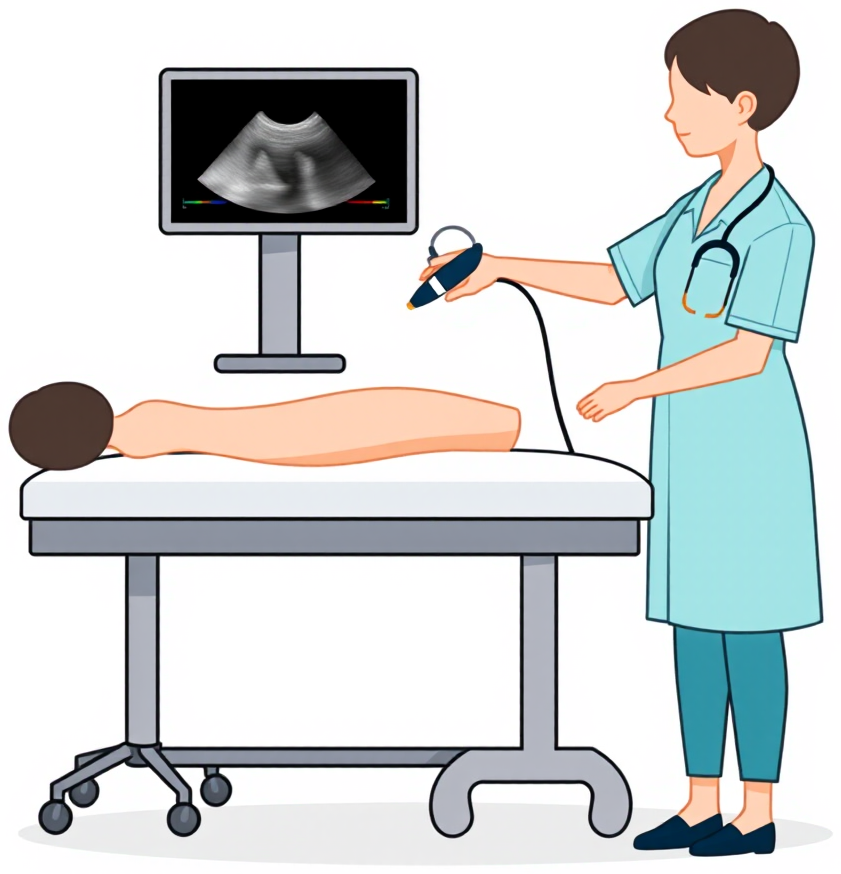
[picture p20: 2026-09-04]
docs/poster-motivation-bibliography/images/ultrasound.png

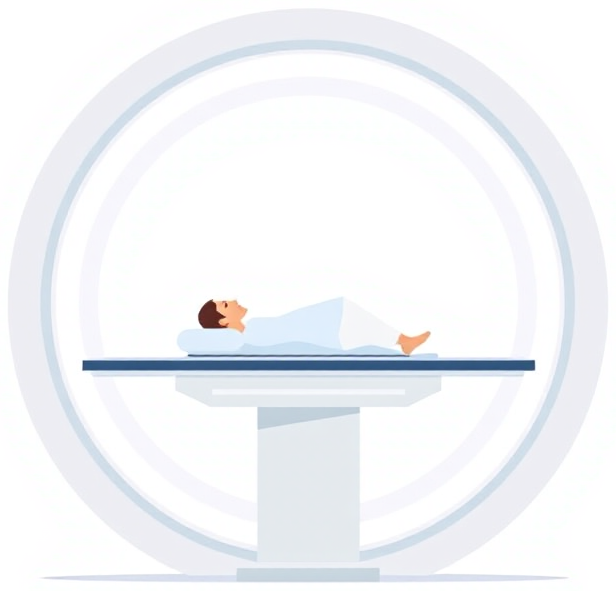
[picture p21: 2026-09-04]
docs/poster-motivation-bibliography/images/ct.png

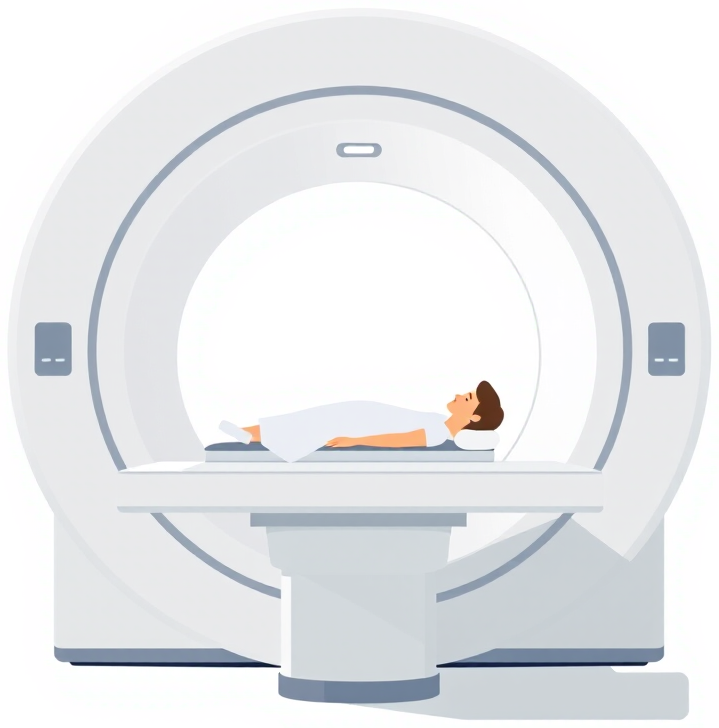
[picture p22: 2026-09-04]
docs/poster-motivation-bibliography/images/mri.png

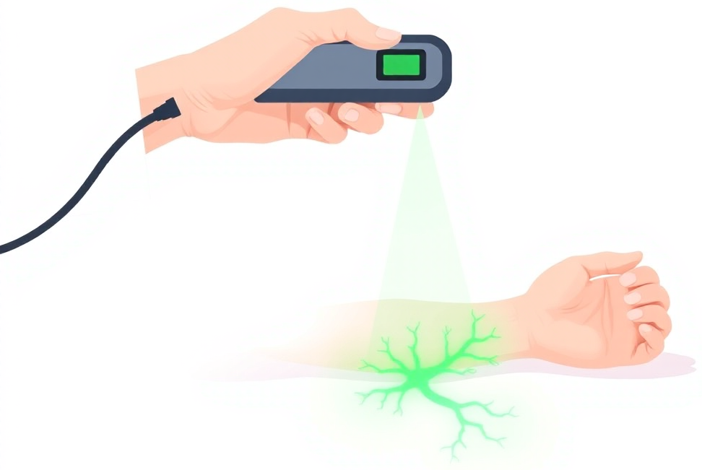
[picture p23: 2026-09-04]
docs/poster-motivation-bibliography/images/nir.png

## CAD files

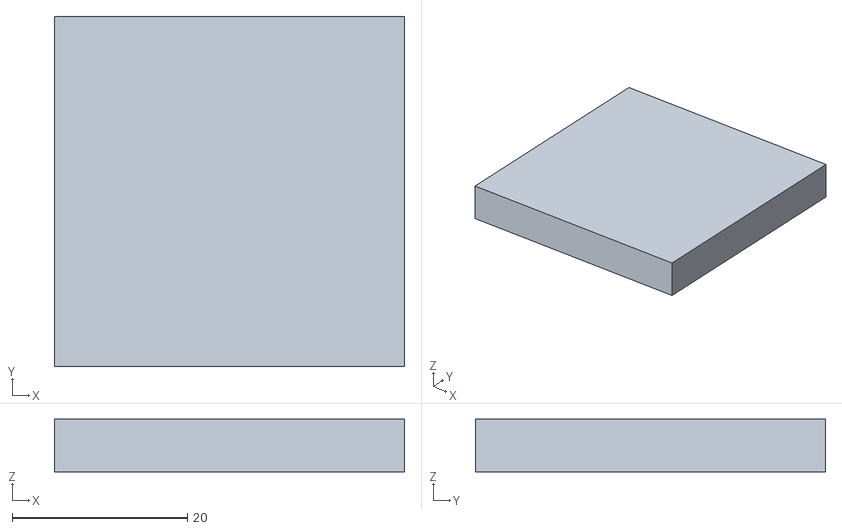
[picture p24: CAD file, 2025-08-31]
difftactile/meshes/vascular-phantom-fragment.stl
40.0 x 40.0 x 6.00

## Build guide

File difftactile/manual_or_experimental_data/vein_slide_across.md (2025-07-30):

In [6]: s.execute_trajectory(0)
target 0 (pose: [-382.1576   85.3686   28.      180.        0.        0.    ]) reached at frame: 60!
target 1 (pose: [-382.1576   85.3686   24.      180.        0.        0.    ]) reached at frame: 77!
target 2 (pose: [-317.1576   85.3686   24.      180.        0.        0.    ]) reached at frame: 169!
target 3 (pose: [-317.1576   65.3686   24.      180.        0.        0.    ]) reached at frame: 205!
target 4 (pose: [-382.1576   65.3686   24.      180.        0.        0.    ]) reached at frame: 297!
target 5 (pose: [-382.1576   45.3686   24.      180.        0.        0.    ]) reached at frame: 333!
target 6 (pose: [-317.1576   45.3686   24.      180.        0.        0.    ]) reached at frame: 425!
target 7 (pose: [-317.1576   25.3686   24.      180.        0.        0.    ]) reached at frame: 461!
target 8 (pose: [-382.1576   25.3686   24.      180.        0.        0.    ]) reached at frame: 554!
target 9 (pose: [-382.1576    5.3686   24.      180.        0.        0.    ]) reached at frame: 590!
target 10 (pose: [-317.1576    5.3686   24.      180.        0.        0.    ]) reached at frame: 683!
target 11 (pose: [-317.1576  -14.6314   24.      180.        0.        0.    ]) reached at frame: 719!
target 12 (pose: [-382.1576  -14.6314   24.      180.        0.        0.    ]) reached at frame: 812!
target 13 (pose: [-382.1576  -34.6314   24.      180.        0.        0.    ]) reached at frame: 849!
target 14 (pose: [-317.1576  -34.6314   24.      180.        0.        0.    ]) reached at frame: 941!
target 15 (pose: [-317.1576  -54.6314   24.      180.        0.        0.    ]) reached at frame: 978!
target 16 (pose: [-382.1576  -54.6314   24.      180.        0.        0.    ]) reached at frame: 1077!
target 17 (pose: [-382.1576  -74.6314   24.      180.        0.        0.    ]) reached at frame: 1114!
target 18 (pose: [-317.1576  -74.6314   24.      180.        0.        0.    ]) reached at frame: 1207!
target 19 (pose: [-317.1576  -94.6314   24.      180.        0.        0.    ]) reached at frame: 1243!

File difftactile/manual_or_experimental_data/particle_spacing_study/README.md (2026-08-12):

# Particle-spacing refinement study

Why: in the shipped configuration the ViTacTip FEM particles (green) **ghost into**
the MPM phantom particles (blue) — the two bodies interpenetrate instead of the
sensor deforming against the phantom surface. The fix is to refine the "atom"
spacing of both bodies so the contact stencil can resolve the interface.

## Result

**Multiplication factor 0.5 produced the desired deformation.** At 0.5 the two
bodies are cleanly separated with a distinct interface; the baseline shows green
particles buried inside the blue block. Compare, both at t=40 s:

| | |
|---|---|
| `iteration_baseline_1.0/shot_08_t040s.png` | ghosting — sensor sunk into the phantom |
| `iteration_0.5/shot_08_t040s.png` | clean contact interface, no interpenetration |

Factors 0.25 and 0.125 were **not run** — see "Why the finer factors were not run".

## What each knob was set to

Everything is driven from the single-source-of-truth files by `set_spacing.py`;
generated files (`system-params.json` distances, `system-params-computed.json`)
are produced from them by `script_apply_scaling` / `script_pre_main`.

| Knob | Baseline | factor 0.5 |
|---|---|---|
| `phantom.mpm_grid_cube_size` (SI) | 0.002 m | 0.001 m |
| `phantom.particle_spacing` (SI) | 0.001 m | 0.0005 m |
| `rigid_static.particle_spacing` (SI) | 0.001 m | 0.0005 m |
| `gmsh_mm.vitactip.characteristic_length_factor` | 0.30 | 0.15 |
| `gmsh_mm.vein.characteristic_length_factor` | 0.30 | 0.15 |
| `contact.dt_override` | 1e-5 s | 5e-6 s |

`particle_spacing` is always `mpm_grid_cube_size / 2` (8 particles per cell in
3D), and the two `characteristic_length_factor` values are always kept equal.
A *smaller* Gmsh factor means a *finer* mesh, so it scales the same way as the
distances.

## The timestep

`contact.dt_override` is the live knob. `Contact.set_dt()`
(`difftactile/main/main.py:2426`) reads it directly; the
`calculate_cfl_timestep(...)` call right above it is commented out, so nothing
auto-computes the timestep. The sibling key `contact.dt` is dead — no code reads it.

It is scaled **linearly** with the spacing. CFL gives `dt ≲ C·Δx/c`, and the wave
speed `c = sqrt((λ+2μ)/ρ)` depends only on material properties, which this study
does not touch. So halving the spacing halves the stable timestep.

## A geometry bug this uncovered

Refining the grid initially moved the phantom out from under the sensor, so the
press-and-slide never made contact. Cause: in `pre_main.py` the phantom's world
origin was derived purely from grid *node indices* times `d`. The zero-velocity
boundary band is a fixed **4 nodes** wide, so its physical extent `4·d` halved on
every refinement, translating the phantom (baseline origin `[0.095, 0.095, 0.045]`
collapsed to `[0.061, 0.061, 0.011]` at factor 0.25). The sensor start pose is
built from `phantom_closest_vertex` minus a *fixed* `sensor_xy_radius`, so the gap
between them grew and the trajectory fell short.

Fix (`pre_main.py`): keep the boundary band at 4 nodes — that requirement is
genuinely measured in cells — but anchor the phantom's world placement to a
reference grid spacing via `_origin_offset()`, absorbing the difference into the
padding in x/y and adding it explicitly in z. The origin now stays within a
quarter-cell of baseline at every factor tested.

## Why the finer factors were not run

Refining by 2× in 3D gives 8× the particles and 8× the grid cells. The MPM state
is stored as `(num_sub_frames, num_particles)` fields with `num_sub_frames = 125`,
so at factor 0.25 the phantom reaches 682,344 particles and those fields alone
need **~15.4 GB**, plus ~2.4 GB of grid fields — against a 10 GB RTX 3080. Both
0.25 and 0.125 died with `CUDA_ERROR_OUT_OF_MEMORY` during field allocation, before
any timestep ran. Factor 0.125 would need roughly 8× more again.

Running them against host RAM on the CPU arch was considered and deliberately
rejected. Factor 0.5 already removes the ghosting, so the finer levels were not
pursued.

## Files

- `set_spacing.py` — scales every spacing knob (and `dt_override`) by one factor.
- `run_one_iteration.sh` — runs one already-configured iteration and screenshots it.
- `run_spacing_sweep.sh` — the full sweep driver (configure → re-mesh → run → capture).
- `iteration_<f>/` — screenshots (`shot_NN_tNNNs.png`, every 5 s), `sim.log`, and
  the per-step regeneration logs for that factor. **Not tracked in git** (see
  `.gitignore`) — these are run output; re-create them with the commands below.

## Reproducing

taichi lives only in the `difftactile` container, and the GGUI window has to
actually render for screenshots to exist, so the container draws into a
**host-side Xvfb** virtual display which `ffmpeg -f x11grab` captures. A virtual
display is used rather than the real one so the run neither disturbs nor captures
the user's desktop.

```bash
./docker/docker-run.sh
Xvfb :95 -screen 0 1280x1024x24 -nolisten tcp &
python3 difftactile/manual_or_experimental_data/particle_spacing_study/set_spacing.py 0.5
docker exec -e DIFFTACTILE_HEADLESS=1 difftactile bash -lc 'cd /workspace/shallow-vessel-palpation-simulator-and-AI \
  && python -m difftactile.scripts.script_apply_scaling \
  && python -m difftactile.scripts.script_generate_vitactip_mesh_gmsh \
  && python -m difftactile.scripts.script_generate_vein_mesh_gmsh \
  && python -m difftactile.scripts.script_pre_main'
./difftactile/manual_or_experimental_data/particle_spacing_study/run_one_iteration.sh 0.5 60 9
```

The `characteristic_length_factor` change only takes effect once the Gmsh meshes
are rebuilt, hence the two `generate_*_mesh_gmsh` steps.

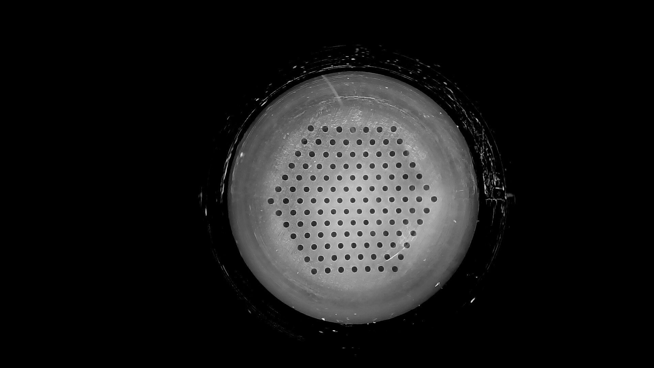
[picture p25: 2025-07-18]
difftactile/manual_or_experimental_data/vitactip_photo_default_state_1920_1080.jpg

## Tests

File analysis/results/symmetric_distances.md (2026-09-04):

# Symmetric nearest-neighbour distances (poster table)

Definition used on the poster (`symmetric_all`): every scored element (marker of a central
video frame / pixel of a top-view map) measures the distance to the nearest ground-truth
element carrying the label the model PREDICTED for it (predicted vessel -> nearest true
vessel; predicted background -> nearest true background). TP and TN contribute 0, FP and FN
contribute > 0. All distances of a model are pooled and averaged once (mean); infinite
distances (no ground-truth element of that label in the frame/map) are dropped.
Frame space: threshold 0.5, markers in 1920x1080 px, 55 px = 2 mm. Map space: 1 px = 1 mm,
the manuscript's runs and operating points; the recomputed one-directional means match
Table 4 exactly.

| Model | space | FG IoU | symmetric, all elements (mm) | symmetric, FP+FN only (mm) | one-directional, Table 4 (mm) | ASSD (mm) | n elements |
|---|---|---|---|---|---|---|---|
| Sim→Sim | video frame (marker) | 0.19 | 0.66 | 3.74 | 3.03 | 2.54 | 85725 |
| Sim→Sim | top-view map (pixel) | 0.42 | 0.13 | 1.86 | 1.05 | 0.75 | 3102 |
| Sim→Silicone | video frame (marker) | 0.24 | 0.52 | 2.82 | 2.16 | 2.13 | 15118 |
| Sim→Silicone | top-view map (pixel) | 0.28 | 0.13 | 1.60 | 1.21 | 1.49 | 18000 |
| Sim→Meat | video frame (marker) | 0.17 | 1.21 | 4.95 | 4.12 | 3.44 | 26919 |
| Sim→Meat | top-view map (pixel) | 0.21 | 0.43 | 6.87 | 5.49 | 4.36 | 74981 |
| Meat→Silicone | video frame (marker) | 0.16 | 2.46 | 4.67 | 3.87 | 3.27 | 14040 |
| Meat→Silicone | top-view map (pixel) | 0.31 | 0.14 | 1.75 | 1.31 | 1.50 | 18000 |

Map space, symmetric over swept pixels only (pixels the sensor passed over): Sim→Sim 0.28 mm, Sim→Silicone 0.27 mm, Sim→Meat 1.54 mm, Meat→Silicone 0.28 mm

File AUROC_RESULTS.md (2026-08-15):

# Ranking metrics across the six canonical scenarios

Per-node vessel-classification AUROC and average precision (AP) for each
(train -> test) configuration, scored twice: once from the published Zenodo
checkpoint and once from a checkpoint retrained locally with `--train`.

Datasets: **A** = simulation, **B** = real silicone phantom, **C** = real meat phantom.

Both metrics are **threshold-free and ranking-based**: they read only the
ordering of the predicted probabilities, never their absolute scale, so no
decision threshold is chosen anywhere in this table. That is deliberate - in a
sim-to-real setting the output *scale* is the first thing to shift between
domains, and a single-threshold score would confound that with what the model
actually learned.

They are reported together because each is blind to something the other sees:

- **AUROC** normalises false positives by the total negative count. On this
  heavily imbalanced problem a large absolute number of false alarms barely
  moves it. Its baseline is always 0.5, which makes it comparable across papers.
- **AP** ignores true negatives entirely, so the negative majority cannot
  flatter it. Its baseline is the **positive rate**, given in the `Chance`
  column, so AP must be read against that - hence the `Lift` column
  (AP / chance), which is how many times better than random ranking the model is.

### Intersection over union

Also reported, at decision threshold **0.5**, over the same
frame-by-frame marker predictions (**not** the reprojected bird's-eye phantom map,
whose separate IoU comes from `vessel_map.sh`):

- **Foreground IoU** — the *vessel present* class. Note this is the agreement between
  prediction and ground truth over that class, `|pred AND true| / |pred OR true|`, not
  "what the ground truth says" or "what the prediction says" on its own.
- **Background IoU** — the same for *vessel absent*. Always the flattering number: the
  negative class is ~89% of nodes on silicone and ~93% on meat, so even a poor model
  overlaps with it heavily. The foreground number is the informative one.

Unlike AUROC and AP, IoU **depends on the decision threshold**, so it carries every
caveat about that choice. It is reported because it is the intuitive quantity, not
because it is the most trustworthy one.

ROC curves: `difftactile/output/roc_curves/roc_curve_<config>_<weights>.pdf`
PR curves:  `difftactile/output/pr_curves/pr_curve_<config>_<weights>.pdf`

| Scenario | Train -> Test | Weights | AUROC | AP | IoU fg | IoU bg | Chance | Lift | Nodes | Positive |
|---|---|---|---|---|---|---|---|---|---|---|
| A-to-A [pretrained] | train on simulation (A), test on held-out simulation (A) | pretrained | **0.9569** | **0.4855** | **0.1809** | 0.8035 | 0.0421 | 11.54x | 85725 | 3607 (4.2%) |
| A-to-B [pretrained] | train on simulation (A), test on silicone (B) | pretrained | **0.7832** | **0.3255** | **0.2394** | 0.7985 | 0.1133 | 2.87x | 15240 | 1727 (11.3%) |
| C-to-B [pretrained] | train on meat (C), test on silicone (B) | pretrained | **0.7874** | **0.3481** | **0.1572** | 0.3713 | 0.1133 | 3.07x | 15240 | 1727 (11.3%) |
| A-to-C [pretrained] | train on simulation (A), test on meat (C) | pretrained | **0.8405** | **0.2279** | **0.1669** | 0.7169 | 0.0651 | 3.50x | 27813 | 1810 (6.5%) |

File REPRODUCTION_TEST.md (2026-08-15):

# Clean-slate reproduction log (2026-08-15)

A fresh clone into an empty directory (`/tmp/vessel-clean-slate/`), the data bundle
downloaded from the published Zenodo record, and every entrypoint run in a **second,
freshly started container** (`VESSEL_PALPATION_CONTAINER=vessel-palpation-clean`) —
nothing reused from the development checkout. Repository state: commit `2e01dab`.

| Step | Result |
|---|---|
| `git clone` (SSH URL; the https URL needs the repository to be public) | OK |
| DOI `10.5281/zenodo.21900934` → `https://zenodo.org/records/21900934`; `wget .../files/shallow-vessel-palpation-data.tar.gz` | 288 023 322 bytes, sha256 `ca540cb3…1a34fe` (matches the local build) |
| `./data/restore_data.sh <tarball>` | all expected paths present |
| `docker-build.sh` (cached) → `docker-run.sh` → `run_pipeline.sh check` | GPU, torch, taichi, torch_geometric, config, data: OK |
| `run_pipeline.sh sim-short` | 8 trials collected, "all done"; exit 139 (known GGUI teardown segfault after writing) |
| `run_pipeline.sh A-to-A / A-to-B / A-to-C` (published best-of-five checkpoints) | AUROC 0.9585 / 0.7832 / 0.8405, AP 0.492 / 0.326 / 0.228, FG IoU 0.185 / 0.239 / 0.167 |
| `run_pipeline.sh C-to-B` (train, seed 42, 48 s) | AUROC 0.6755, AP 0.281, FG IoU 0.145 (a single seed — inside the published five-seed spread) |
| `score_all_scenarios.sh --pretrained` | table + 8 ROC/PR PDFs |
| `score_all_scenarios.sh --seeds 2` | 4 configurations × 2 seeds trained and summarised (354 s) |
| `ablation_clip_len.sh --seeds 1` | clip lengths {1,3,5,7} trained and ranked (152 s) |
| `vessel_map_all.sh` | first run failed on the Silicone maps: the photo ground-truth mask is not in the bundle → **fixed** (built on first use, `2e01dab`); re-run: all six maps, thresholds identical to the published runs (0.6283 / 0.5739 / 0.5990 / 0.6129 / 0.6183; Sim→Meat F1 fallback 0.5530), video-vs-photo truth IoU 0.2934 |
| `vessel_map_sim_trajectory.sh` | posed slide simulated and reordered (77 s; exit 139 after writing) |
| `alignment_figures.sh` | MAE 11.87 / 15.82 / 14.53 / 12.42 px (press / twist-z / twist-x / slide) |
| `script_frame_space_metrics` | `FRAME_SPACE_METRICS.md` identical to the published one |
| `domain_adaptation.sh` (joint BO, `DIFFTACTILE_BO_ITERATIONS=2 DIFFTACTILE_BO_RANDOM=1`) | ran to completion (493 s), wrote results + validation on the four interactions; exit 139 after writing |
| `score_params.sh` | vpn 0.905, van 0.075, objective +0.830 |
| `record_da_trajectories.sh` | four .mp4 recorded (exit 139 after writing) |
| `view_predictions.sh A-to-C --record`, `annotate_data_bare_metal.sh --meat --record`, `record_videos.sh --predictions` | recorded offscreen, compressed into `videos/` |

Notes: every exit code 139 is the documented Taichi GGUI teardown segfault that happens
*after* the run has printed its completion message and written its outputs. Running the
sweep, the ablation and DA in a clone rewrites `AUROC_RESULTS.md`, `CLIP_LEN_ABLATION.md`
and `bo-gp.json` (the BO hand-off file) in that clone, as designed.

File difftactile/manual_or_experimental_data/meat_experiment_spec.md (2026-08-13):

each of the 10 steaks is 5 mm thick

This is the record of what was **recorded**: all 23 runs, including repeats of the
same condition at different sensor heights. Only **10** of them are used by the
model (the union of `MEAT_TRAIN_TRIALS` and `MEAT_VALIDATION_TRIALS` in
`difftactile/cnn/dataset.py`) and only those 10 ship in the Zenodo bundle; the
other 13 were dropped rather than shipped for an end user to puzzle over. They
are marked **[shipped]** below.

On disk the shipped trials carry a descriptive prefix — `20260228-232013` is the
directory `1-metal-straw-beneath-1-steak-20260228-232013` — so the condition is
readable without consulting this file. The timestamp remains the trial's
identity; the prefix is only a label. Note the descriptions here say "straw" for
what the directory names call "metal straw", to distinguish them from the one
silicone-straw trial.

- 20260228-230937: straw on top (z=32) **[shipped]**
- 20260228-231646: straw beneath 1 steak (z=32)
- 20260228-231939: straw beneath 1 steak (z=31)
- 20260228-232013: straw beneath 1 steak (z=30) **[shipped]**
- 20260228-232534: straw beneath 2 steaks (z=30)
- 20260228-232632: straw beneath 2 steaks (z=32) **[shipped]**
- 20260228-233031: straw beneath 3 steaks (z=30) **[shipped]**
- 20260228-233454: straw beneath 4 steaks (z=30) **[shipped]**
- 20260228-233825: straw beneath 6 steaks (z=30)
- 20260228-233958: straw beneath 6 steaks (z=29)
- 20260228-234106: straw beneath 6 steaks (z=28)
- 20260228-234219: straw beneath 6 steaks (z=27)
- 20260228-234337: straw beneath 6 steaks (z=26) **[shipped]**
- 20260228-234613: no straw (z=26)
- 20260228-234824: no straw (z=25) **[shipped]**
- 20260228-235519: 2 straws beneath 2 steaks (z=32)
- 20260228-235639: 2 straws beneath 2 steaks (z=30)
- 20260228-235749: 2 straws beneath 2 steaks (z=29) **[shipped]**
- 20260301-000249: 3 straws beneath 2 steaks (z=32) - noisy signal, only 1 straw visible
- 20260301-000537: 3 straws beneath 2 steaks (z=30) - only 2 straws visible
- 20260301-000735: 3 straws beneath 2 steaks (z=28) - only 2.5 straws visible
- 20260301-000849: 3 straws beneath 2 steaks (z=26) - 3 straws visible **[shipped]**
- 20260301-001457: 1 silicone straw beneath 2 steaks (z=26) **[shipped]**

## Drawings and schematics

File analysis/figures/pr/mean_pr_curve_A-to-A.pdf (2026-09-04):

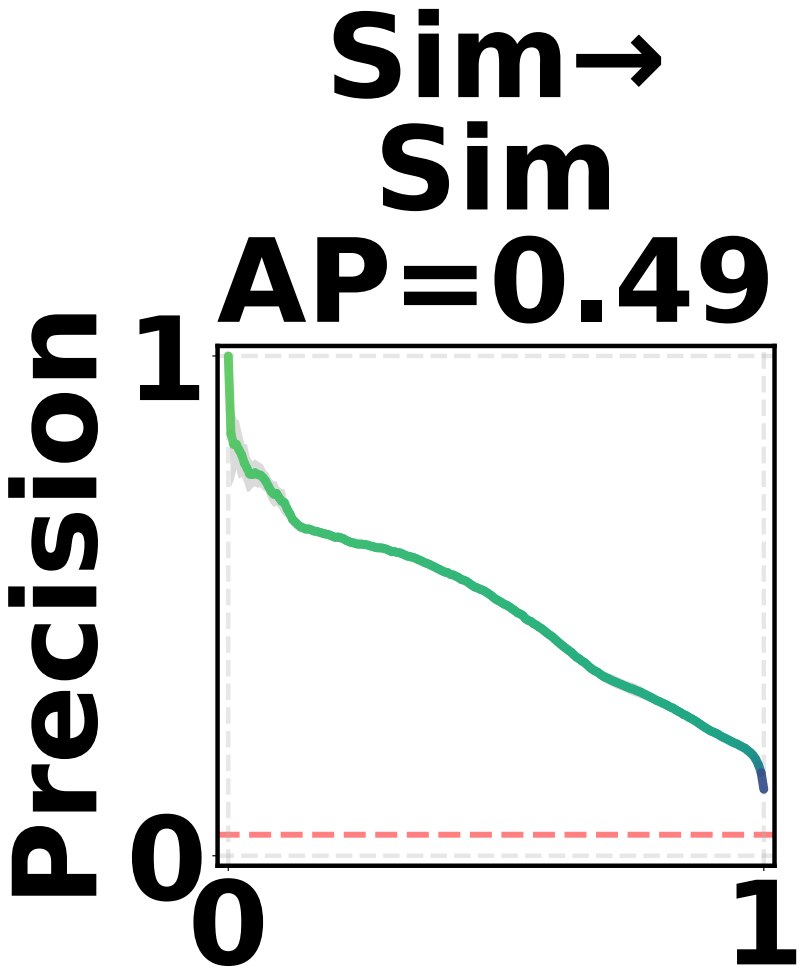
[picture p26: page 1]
Precision; Sim→ Sim AP=0.49

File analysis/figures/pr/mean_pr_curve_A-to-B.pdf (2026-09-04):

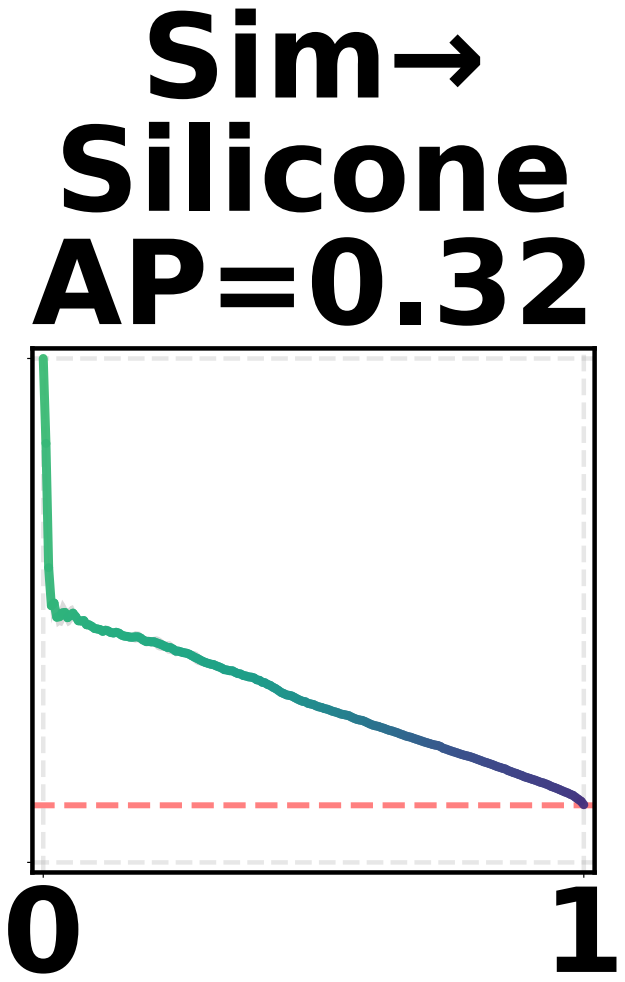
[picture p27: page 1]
Sim→ Silicone AP=0.32

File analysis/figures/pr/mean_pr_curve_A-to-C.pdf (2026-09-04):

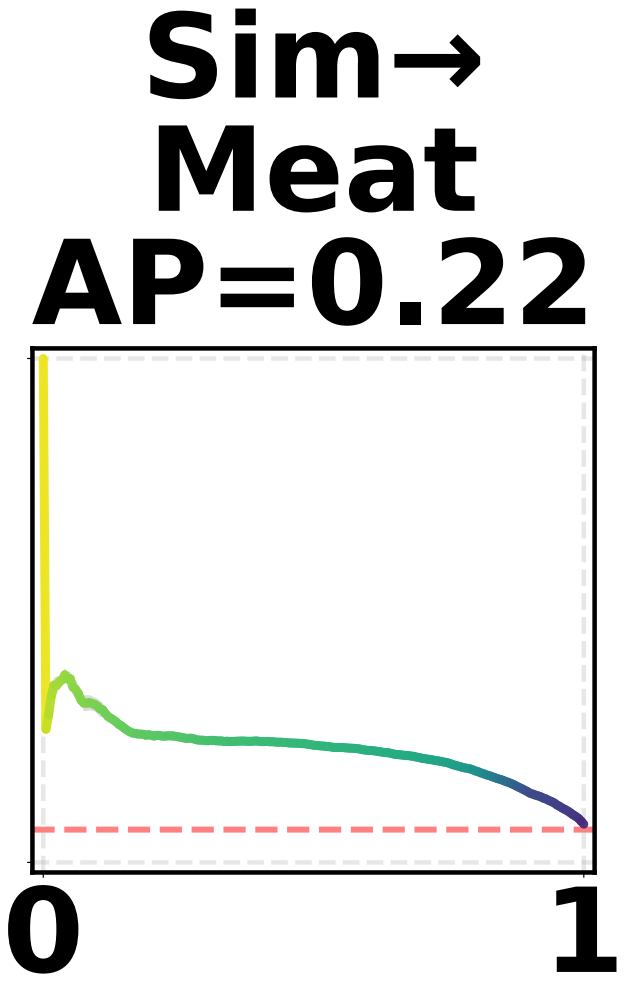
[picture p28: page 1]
Sim→ Meat AP=0.22

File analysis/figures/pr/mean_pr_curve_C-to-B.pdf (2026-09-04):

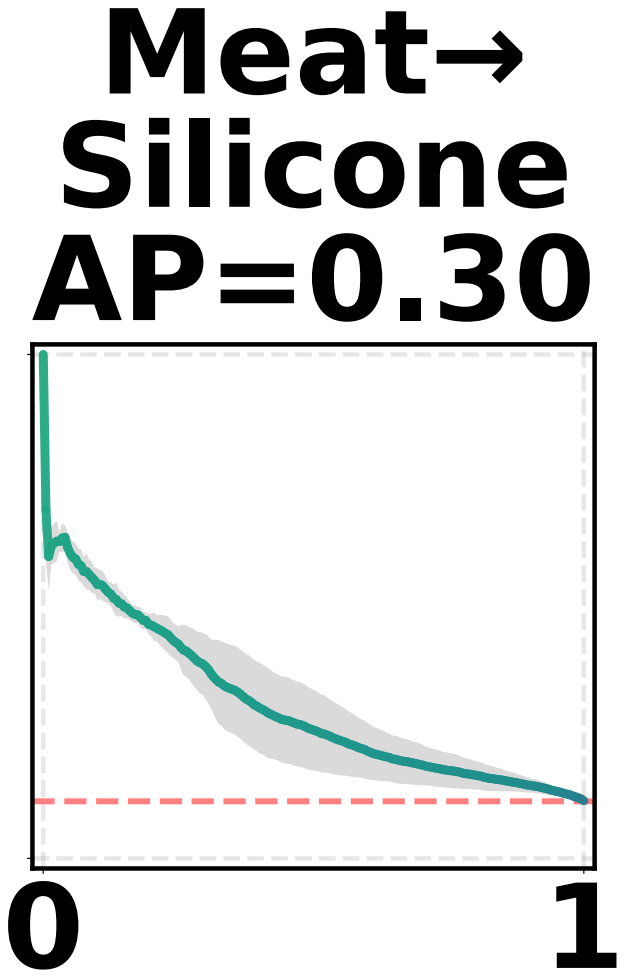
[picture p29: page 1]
Meat→ Silicone AP=0.30

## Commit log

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2025-06-30 decrease sensor stiffness further; make phantom mesh finer; increase search distance for collision checking
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2025-07-10 simplify vitactip material params to be scalars rather than fields; sensor still doesn't deform
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2025-07-22 set up interpolate frame (and loss computation) to work only when the sim vein is within the exp vein bounds; runtime error
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2025-08-07 fail: translate gmsh code to cadquery
    [vitactip_cadquery.stl]
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2025-08-13 modify marker augmentations such that each video frame has different markers missing
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2025-08-19 about to collect training data - easy, stable straight-line slide w/o marker jitter
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2025-08-20 implement joint dataset (easy straight-line motion and difficult random jittery motion with lots of curves and turns)
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2025-08-22 fix localisation map; ground truth from video displays fine on the localisation map
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2025-08-27 simulation doesn't work; I get ghosting despite having effective particle spacing = 2mm and a low courant number
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2025-08-29 fix deformation bug related to flat ViTacTip, get good differential deformation (i.e. sensor deforms a lot on vein contact but very little on phantom contact), implement vein as a separate object
2025-08-30 fix bug where vitactip particles were nan by disabling dynamic material parameter updates
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2025-08-31 make sure that the sim trajectories are exactly the same as the exp ones (angles of correct sign applied to correct axes, sensor rotation offset has correct sign, slide in correct direction)
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2026-08-11 docs: rewrite README from scratch and add CLAUDE.md
    Replace the inherited upstream DiffTactile README with one describing
    this fork: sim-to-real subsurface feature localisation with a ViTacTip
    sensor.
    Covers setup, the JSON-based configuration model (and which files are
    generated vs. hand-edited), exact run commands for every entrypoint, the
    simulation and ML pipelines, and the parallel experiment branches
    (iros / sim-to-silicone / sim-to-meat-test).
    Documents the reproducibility caveats honestly: datasets and trained
    weights are gitignored and absent from a clean clone, several absolute
    paths point at the original machine, training is disabled behind early
    returns, a CUDA GPU is required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
2026-08-11 Dockerise, unify the three scenarios on one branch, add data bundle
    Reproducibility work: the repository can now be run end-to-end by someone else,
    from a clone plus a published data bundle.
    Docker (docker/, the officially supported path)
    - nvidia/cuda:12.6.3-devel-ubuntu22.04 base with ONE system Python 3.10 (no
    conda/micromamba): Taichi, torch 2.8.0+cu126 and torch-geometric coexist.
    - X11 passthrough for the Taichi GGUI / Gmsh / cv2 windows; --ipc host for
    DataLoader workers; container runs as the invoking user so artifacts written
    into the bind-mounted repo are not root-owned.
    - run_pipeline.sh wraps every stage: check, sim-short, sim-full, and the three
    scenarios.
    Path resolut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
2026-08-11 docs: correct runtime estimates and bundle size from measurement
    The full simulator run was documented as ~1 hour; measured on an RTX 3080 it is
    ~14.1 s/trial, so 800 trials takes ~3 hours. Corrected in README, CLAUDE.md,
    run_pipeline.sh --help, MANIFEST.md and make_data_bundle.sh, along with the
    bundle size (190 MB compressed, not 186 MB) now that the sensor-geometry and
    system-identification artifacts are included.
    Also refreshes the branch table and the "a display is mandatory" requirement,
    both of which predate the unified branch and headless support.
2026-08-11 fix: resolve checkpoint and test-loader paths against the repo root
    iros_gnn still opened saved_models_iros/ and test_loader_gnn_iros.pickle
    relative to the current working directory, so those four call sites only worked
    when launched from the repository root - the one constraint the rest of this
    work removed. Route them through repo_path() like everything else, create the
    parent directory before writing, and print where the checkpoint landed.
    Verified: sim-to-silicone still gives AUC 0.6785678, and sim-to-meat writes its
    checkpoint to the absolute path.
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2026-08-11 docs: record the completed overnight run and verify trajectory selection
    Full sim-full run finished: 100 loops / 800 trials in 9905 s (2 h 45 m), exit 0,
    no errors, no corrupt files, exactly 200 of each trajectory type, type 3 at
    316-317 frames matching the published dataset.
    Also completes the verification left pending in the previous commit: a run with
    DIFFTACTILE_TRAJECTORIES=3 produces only type-3 trials at 317 frames, so the
    published dataset is now regenerable. Timing estimates replaced with the
    measured figure throughout.
2026-08-12 docs: state that main is the only supported branch
    Only `main` is meant to be used by end users, and only `main` is
    maintained going forward. The historical per-experiment branches are
    frozen snapshots kept so the code behind a published result stays
    recoverable, not starting points for new work.
    - README: branches section leads with "use main, ignore the rest" and a
    status column marking main supported, iros/sim-to-silicone frozen and
    sim-to-meat-test obsolete; both clone snippets note they land on main.
    - CLAUDE.md: explicit instruction to make every change on `main`, not to
    revive or merge historical branches, and to keep only `main`'s docs
    current. Replaces the previous instruct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
2026-08-12 docs: document the upstream-difftactile tag, drop deleted-branch references
    The development branches have been removed from this repository, so the
    Branches section no longer described reality. Rewrite it as "Branches and
    tags": state that main is the only branch, and document the
    upstream-difftactile tag as the fork point, with the diff command that
    separates upstream code from this project's contribution.
    Also updates the three places that referred to the removed branches as if
    they still existed (quickstart note, endgame stage description, and the
    meat-trial row of the missing-data table).
2026-08-12 docs: drop remaining references to the removed development branches
    main is now the only branch, so phrasing like "the only supported branch"
    and "no branch switching" implied alternatives that no longer exist.
    Removes the note about the development history being available on request,
    and relocates the meat-trial spec pointer into the meat preprocessing
    section, where it is actually relevant.
2026-08-12 docs: record the published Zenodo DOI and download URL
    The dataset bundle is now published as Zenodo record
    shallow-vessel-palpation-dataset (DOI 10.5281/zenodo.21900934), so the
    placeholder <RECORD_ID> in the README quickstart is replaced with the real
    URL, and the pipeline's "data missing" hint now prints the exact wget line.
    CLAUDE.md additionally documents the offline restore route (restore_data.sh
    takes any local tarball or unpacked directory) for testing without touching
    Zenodo.
2026-08-12 chore: remove dead code and unused assets (DEAD_CODE_ANALYSIS categories A-C)
    Deletes the files and folders flagged as dead in DEAD_CODE_ANALYSIS.md, at
    file/folder granularity only — no partial edits to files that remain.
    - Category A: superseded one-off analysis scripts, empty files, and the
    root-level sitecustomize.py (Python auto-imports any module of that name at
    interpreter start-up, so an empty one is worth removing outright).
    - Category B: the legacy U-Net path (cnn/train.py, lit_module_unet_cnn.py and
    their wrapper), broken entrypoint wrappers (script_all, script_benchmark_dataset,
    script_hungarian_exp, script_cfl_and_contact_params_estimation), and the
    sandbox/ and ml_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
    [cylinder.stl, suturing-phantom.stl, thin-long-indenter.stl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]
2026-08-12 docs: record the blank-slate re-run and the GGUI teardown segfault
    Re-ran the full quickstart in a fresh clone at the dead-code-removal commit:
    check, all three paper configurations, and sim-short. A-to-B reproduces
    AUC 0.6785678641614648 bit-identically and A-to-C gives IoU 0.808/0.197, so
    nothing live was removed.
    The run also surfaced a long-standing crash: script_main exits 139 during
    CUDA/GGUI teardown whenever a display is present. A 2x2 over {commit before
    removal, after} x {GUI, headless} pins it to the GUI alone -- the commit before
    the sweep crashes identically -- so it predates this work. It fires after
    main() prints "all done", and the collected trajectories are complete and val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
2026-08-12 fix: keep the phantom's world placement invariant under grid refinement
    The phantom's origin was derived purely from MPM grid node indices times the
    grid spacing d. The zero-velocity boundary band is a fixed 4 nodes wide, so its
    physical extent 4*d halved on every refinement, translating the phantom away
    from the sensor: the baseline origin [0.095, 0.095, 0.045] collapsed to
    [0.061, 0.061, 0.011] at a quarter of the original spacing.
    The sensor start pose is built from phantom_closest_vertex minus a *fixed*
    sensor_xy_radius, so the gap between the two grew and the press-and-slide
    trajectory stopped making contact altogether.
    Keep the band at 4 nodes -- that requirement is genuinely measure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
2026-08-12 fix: keep min_coords on the MPM grid lattice in z
    Regression from 28b4797. That commit compensated for the shrinking boundary band
    by adding _origin_offset() to min_coords in z, but left the grid node indices
    alone. The contact kernels (check_grid_occupy, collision0/1) reconstruct a grid
    node's world position as (index + 0.5) * d, so shifting min_coords off the node
    lattice desynced the collision geometry from where the phantom actually sits --
    by 0.02, i.e. 4 cells, at the current spacing.
    Concretely: min_ixs[2] was 4, which the kernels place at 0.0225, while
    min_coords[2] said 0.0425. In x/y the padding had absorbed the offset into the
    index, so those axes stayed consistent and only z dri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
2026-08-12 Revert "sim: halve the FEM/MPM particle spacing"
    Restore the original spacing, timestep and display radius:
    phantom.mpm_grid_cube_size 0.001 -> 0.002 m
    phantom.particle_spacing 0.0005 -> 0.001 m (grid/2, 8 PPC)
    rigid_static.particle_spacing 0.0005 -> 0.001 m (kept in sync)
    characteristic_length_factor 0.15 -> 0.30 (vitactip and vein, in sync)
    contact.dt_override 5e-6 -> 1e-5 s
    visualisation.particle_size_normal 4.5e-4 -> 9e-4
    620358f already recorded that the refinement did not fix the sensor ghosting, so
    it was not buying anything the 8x particle count and 2x timestep cost was worth.
    Reverting also restores headroom on the 10 GB card.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
2026-08-12 sim: add DIFFTACTILE_VEIN_PAIR to collect the with/without-vein pair
    Each training-data collection loop runs two substeps, and the first was meant to
    enable the sensor<->vein contact pair so the same trajectory is swept once with a
    subsurface vein and once without -- the contrast the GNN is trained to detect.
    That half was hard-disabled by `if False and j < 1`, so in practice every substep
    ran with collision_ixs = [0] and the vein never made contact.
    Gate it on DIFFTACTILE_VEIN_PAIR instead of flipping the literal. The default is
    0, so committed behaviour is unchanged; set it to 1 to collect the pair. Also
    print the resolved collision_ixs per substep, since "is the vein actually in
    contact?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
2026-08-12 docs: document the two deliberate modelling decisions as limitations
    Rename "Known issues" to "Limitations and known issues" and lead with the two
    choices that shape how the simulator's output should be read.
    Asymmetric contact compliance: the sensor<->phantom pair is tuned to transfer
    very little deformation to either body, so visible sensor deformation is driven
    almost entirely by the sensor<->vein pair. The simulator is a targeted model of
    the subsurface feature's mechanical signature rather than a general soft-body
    contact solver -- the validated output is the marker displacement field, which is
    what the GNN consumes and what matches the real ViTacTip across all four
    domain-adaptation t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
2026-08-12 chore: drop pre-rename bundle compatibility shims
    The rebuilt, post-rename bundle is now the bundle in use, so nothing needs to
    read a pre-rename archive any more. Removed:
    - legacy_path_for() / resolve_src() in data/restore_data.sh and
    data/make_data_bundle.sh, which mapped each expected path to its old
    conference-derived equivalent
    - data/migrate_bundle_artifacts.py and its invocation from the bundle build,
    which rewrote the names stored inside the pickles and checkpoints
    - LEGACY_MEAT_LOADER_FLAG in cnn/common.py; has_flat_stats() now recognises
    only the current "meat" key
    All of it remains in git history if a pre-rename archive ever needs reading.
    Note the orderi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
2026-08-12 fix: never block a script waiting on a GUI window
    Scripts stopped dead on plt.show(), cv2.waitKey(0), input(), gmsh.fltk.run()
    and tkinter's mainloop(), each waiting for somebody to click a window's close
    button. Fine at a desk, fatal in a container, over SSH or in CI. The existing
    guards only helped when DIFFTACTILE_HEADLESS=1 or DISPLAY was unset, so a
    machine *with* a display still hung — e.g. the A-to-B ROC evaluation inside
    Docker, which sets DISPLAY=:1.
    Add difftactile/main/display.py as the single policy for this, and route every
    blocking call through it. Nothing blocks by default: figures and 3-D views are
    always written to disk (the window was only ever a convenience), viewer loo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
2026-08-12 feat: dataset annotation tooling, results docs, and stale-frame-flash fix
    - docker/annotate_data.sh: one entry point to annotate the silicone dataset
    and review the meat annotations, staging the videos the published bundle
    deliberately omits
    - docker/view_predictions.sh, docker/vessel_map.sh: prediction viewers
    - RESULTS.md / AUROC_RESULTS.md: map the paper's claims to the artifacts
    that reproduce them
    - display.py: run_frame_browser() presents each frame twice per redraw, so
    compositing display servers (Xwayland/Mutter) can no longer flash a stale
    buffer when stepping frames; README documents the latency trade-off
2026-08-12 docs: explain why the vessel-map cache is excluded from the bundle
    exp_probs.npz and the ground-truth mask images read as missing data. Both
    are regenerated from artefacts that ship: the cache from the silicone
    dataset plus the meat checkpoint in under a second, the masks from two
    git-tracked inputs. Record that in the manifest and soften vessel_map.sh's
    --cached note, which implied the cache was an omission.
2026-08-13 feat: run the annotation viewers bare metal in a dedicated env
    The silicone/meat annotation viewers are hand-driven frame by frame and are
    the main tool for debugging wrong frame-by-frame predictions, so they need to
    feel immediate. Running them in the container puts a forwarded X socket on
    every repaint, which made stepping choppy.
    `docker/annotate_data.sh` is now the one entrypoint that runs outside Docker.
    It uses its own micromamba env, `vessel-palpation-annotator`
    (requirements/annotator-env.yml): pinned, ~500 MB, and deliberately minimal -
    numpy, scipy, tqdm and a GUI-capable opencv-python. The last point is
    load-bearing: the project's other envs install opencv-python-headless, which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
2026-08-13 fix: block on keypresses in the frame browsers instead of polling
    The silicone annotator passed a `needs_repaint` callback to
    `run_frame_browser`, which switched the loop from blocking on a keypress to
    waking every 30 ms to re-check a dirty flag the mouse callback set. That put a
    30 ms floor on how fast frames could be stepped and up to 30 ms of dead
    latency in front of every keypress.
    Measured on the real display: render() is 0.5 ms and a full redraw with both
    presents is 6.9 ms, against 31 ms per poll iteration - the poll was ~4.5x
    everything else combined, and is what made stepping through frames choppy.
    The poll only existed so a click would repaint promptly. `cv2.waitKey(0)` is
    what p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
2026-08-13 perf: make the frame browsers' double present opt-in
    The redraw path presented every frame twice to work around rootless Xwayland
    re-presenting a stale buffer on a keypress. It costs a full extra present:
    measured 6.7 ms vs 3.5 ms per frame step, ~45% of the redraw.
    Most compositors do not need it, so it is now off by default and restored with
    DIFFTACTILE_DOUBLE_PRESENT=1 if a keypress briefly shows the previous frame.
    The key wait stays cv2.waitKey(0) - fully blocking, no timer. The three
    remaining short non-zero waits are deliberately not 0: two are pumps that flush
    the paint before blocking (a 0 there would block mid-redraw and demand a
    keypress just to finish painting), and one drains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
2026-08-13 fix: force the X11 backend in the annotation viewers
    Set QT_QPA_PLATFORM=xcb and GDK_BACKEND=x11 in annotate_data.sh rather than
    letting the toolkits autodetect.
    The opencv-python wheel ships exactly one Qt platform plugin - xcb - so on a
    Wayland session these tools go through Xwayland regardless. Naming it makes
    that deterministic: autodetection printed "Ignoring XDG_SESSION_TYPE=wayland on
    Gnome" on every start-up and can abort outright if it picks a plugin the wheel
    does not carry. GDK_BACKEND covers OpenCV builds compiled against GTK.
    Both use ${VAR:-default}, so a user on a build with a real Wayland plugin can
    still override with QT_QPA_PLATFORM=wayland.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
2026-08-13 feat: trim and rename the meat dataset; rework the prediction viewer
    Meat dataset
    ------------
    The experiment recorded 23 trials but only 10 were ever referenced by a split
    (populate_clips_meat already filtered to MEAT_TRAIN_TRIALS | MEAT_VALIDATION_
    TRIALS). The other 13 were repeats of the same condition at different sensor
    heights, so they are dropped rather than shipped in the Zenodo bundle for an
    end user to puzzle over. meat_experiment_spec.md still lists all 23 as the
    record of what was recorded, marking which ten ship.
    Trial directories now carry a descriptive prefix:
    `2-metal-straws-beneath-2-steaks-20260228-235749`. The timestamp remains the
    trial's identity - the raw recordings a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
2026-08-13 fix: bundle from the repo by default, and refuse to ship an incomplete one
    Two related traps in make_data_bundle.sh, both of which would have produced a
    quietly broken Zenodo artifact.
    SOURCE_DIR defaulted to the author's frozen submission-state snapshot outside
    the repository. That tree predates the meat-dataset rename and the checkpoint
    path renames: its meat data is under iros_training_data/ as 23 bare-timestamp
    trials, and saved_models_{sim,meat}/ and test_loader_gnn_*.pickle do not exist
    under those names. The default is now the repository itself, which is the
    authoritative copy of the data; the snapshot is an explicit opt-in.
    copy_tree/copy_file printed "MISSING (skipped)" and return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
2026-08-13 feat: report average precision alongside AUROC; default the viewer to --central
    Three related changes.
    1. --central is now the prediction viewer's default.
    It shows the frames that are actually reported and scored, so it is the view
    that should appear unqualified; --all becomes the opt-in debugging view for the
    off-centre predictions training learns from. Passing both flags is still an
    error - asking for both is contradictory, so neither silently wins.
    2. Average precision reported everywhere AUROC is.
    AUROC normalises false positives by the total negative count, and this problem
    is 7-11% positive, so a large absolute number of false alarms barely moves it.
    AP ignores true negatives enti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
2026-08-13 refactor: route every decision threshold through a named constant
    Six hardcoded probability cuts were scattered across five modules, and they had
    drifted into disagreement: 0.5 in four, 0.58 in two, with nothing saying why
    either number was chosen or that they differed.
    Both now live in cnn/curve_plots.py, which already owned threshold policy:
    DECISION_THRESHOLD = 0.5 the conventional, deliberately untuned cut.
    Drives the IoU logged in shared_step() (both
    segmentation_gnn.py and gnn.py) and the two
    dead U-Net paths in visualise.py.
    MAP_DECISION_THRESHOLD = 0.58 the empirical cut be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
2026-08-13 feat: report foreground/background IoU for every model, with mean/std over seeds
    The manuscript reports an IoU table, but the codebase did not clearly produce
    it. A-to-B --eval reported NO IoU at all - it computed only AUROC and AP - and
    C-to-B and A-to-C emitted it solely inside a Lightning table as `test_iou/0` and
    `test_iou/1`, which never said which class was which.
    marker_iou() now computes both, and score_ranking_metrics() returns them, so all
    three configurations print:
    foreground IoU (vessel present) = ...
    background IoU (vessel absent) = ...
    macro IoU (mean of the two) = ...
    Verified against the Lightning table it replaces: on A-to-C, test_iou/1 =
    0.19748 = foreg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
2026-08-13 feat: A-to-A as a first-class scenario; document how dataset A is split
    The split audit first, since it motivates the rest. create_splits_single_dataset_scheme()
    sorts trajectory filenames and cuts at 70%/85% - 350/75/75 of 500 trajectories -
    with no stratification by any property. That is fine here: EVERY trajectory in
    the shipped dataset contains exactly one vein (vein_polyline is
    (frames, 1, 50, 2) in all 500 files), so "test has two vessels but train saw
    one" cannot arise - there is no such variation to stratify over. Vein-present
    frame fraction is 0.5019 / 0.5029 / 0.5017 across train/val/test. Splitting is
    by TRAJECTORY, so overlapping sliding windows cannot leak between splits.
    Docume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
2026-08-13 fix: bound the domain-adaptation loop; document why Fig. 5 is not reproducible
    Running the new domain_adaptation.sh end to end turned up two pre-existing
    faults in Contact.domain_adaptation(). Both are measured, not inferred, and both
    are now documented so they are not re-diagnosed from scratch.
    1. The PID controller never converges. Its position error sits at a CONSTANT
    0.0982 against a 0.005 tolerance and is byte-identical after 120 timesteps -
    the sensor never moves toward the waypoint at all. The tip vertex the PID
    reads is offset from the pose set_up_pose() sets.
    This is NOT specific to domain adaptation: the TRAINING trajectories show
    exactly the same 0.0982 and also n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
2026-08-13 fix: domain adaptation now runs and reproduces Fig. 5
    The hang was one missing call, not a broken controller - my earlier diagnosis
    in this repository was wrong and is corrected here.
    update() advances vertices_undeformed_A[frame] -> [frame+1] across the
    sub-frames of ONE timestep. copy_frame() copies the result back to frame 0,
    which is where the next timestep's set_control_vel() and the PID both read from.
    collect_training_data() had always called it; the DA loop never did, relying
    instead on memory_to_cache() - which is a no-op, since
    vitactip.memory_to_cache() starts with a bare `return` (a memory optimisation
    for collection). So every DA timestep restarted from the initial pose, the PI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
